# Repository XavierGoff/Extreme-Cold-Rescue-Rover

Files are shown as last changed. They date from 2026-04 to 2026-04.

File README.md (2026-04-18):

# Extreme Cold Rescue Rover

A tracked rescue robot designed to operate in snowy and unstable terrain, with a focus on low ground pressure, robust mobility, and practical field deployment. This project was developed as a fast-turnaround engineering build, combining mechanical design, drivetrain selection, power system integration, and control architecture into a compact rescue platform.

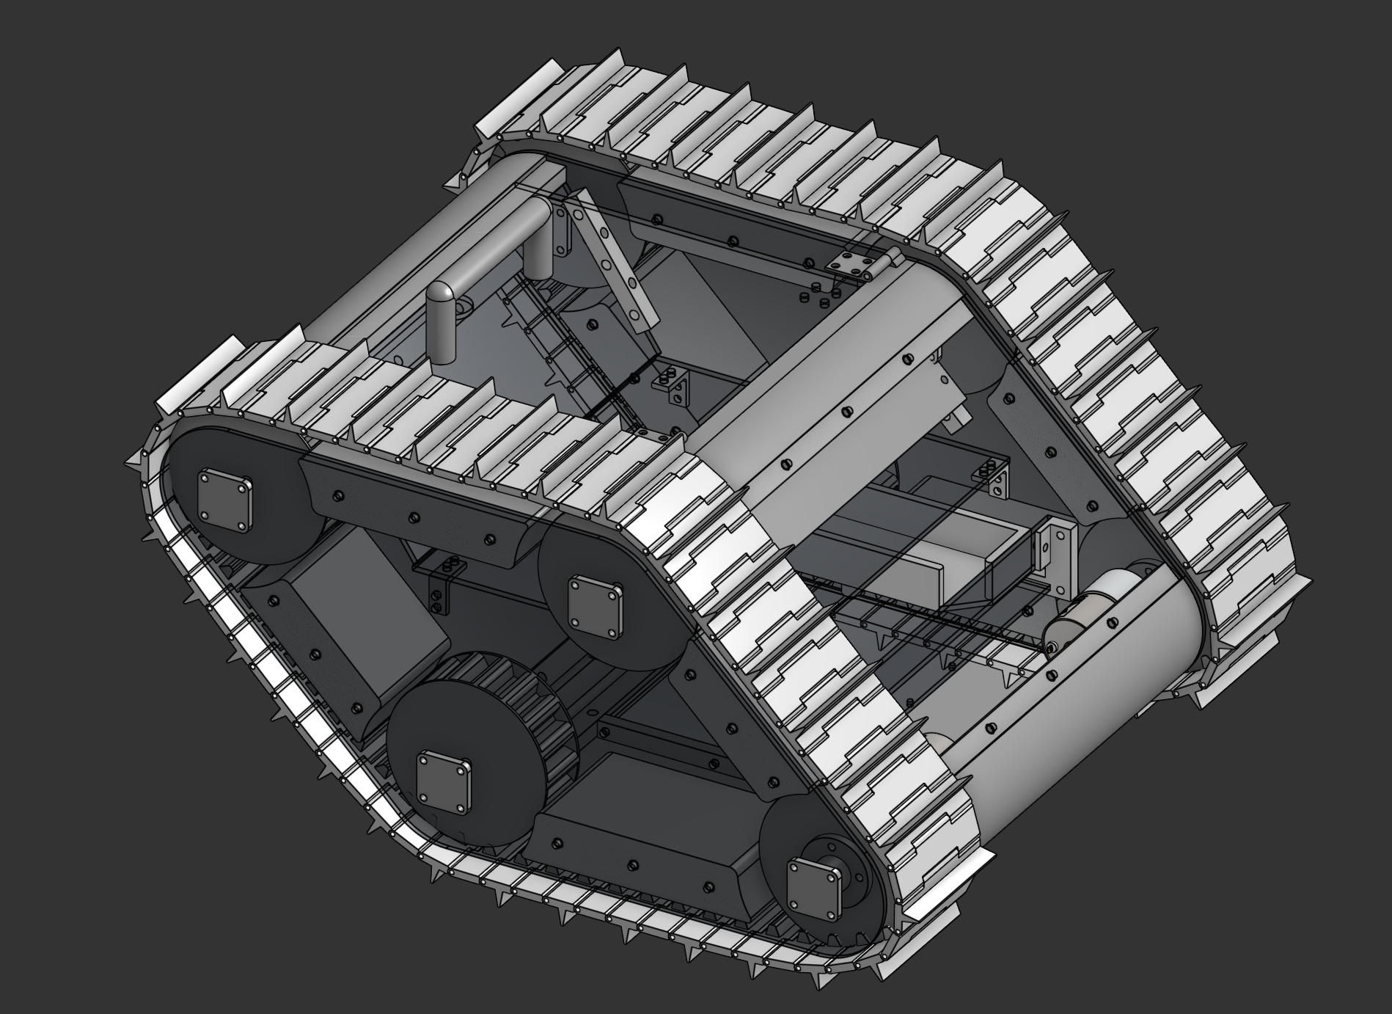
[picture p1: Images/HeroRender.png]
Hero Render


## Overview

This robot was developed to address a simple but difficult problem: how can a small ground robot move effectively across soft snow without sinking, stalling, or becoming unstable?

The project focuses on designing a lightweight tracked platform capable of traversing powdery terrain while carrying its own electronics and drive system. The design process involved balancing traction, footprint area, chassis weight, torque requirements, and manufacturability under tight time and budget constraints.

Rather than treating this as just a remote-controlled vehicle, the project was approached as an engineering system, with attention given to terrain interaction, drivetrain performance, structural layout, and future expandability toward autonomous rescue functionality.

## Key Features

- Tracked drivetrain for improved traction and terrain conformity
- Wide contact area to reduce ground pressure on soft snow
- High-torque drive system for low-speed force output
- Compact chassis designed around integrated electronics and battery packaging
- Modular structure to support iterative redesign and component replacement
- Remote control operation, with future scope for semi-autonomous behaviour

## Engineering Objectives

The main technical goals of the project were:

- Minimise sinking in soft snow by increasing contact area and lowering pressure on the terrain
- Generate sufficient drive torque to maintain motion under resistive snow loading
- Keep overall mass low enough to preserve flotation and reduce drivetrain demand
- Package the electronics cleanly and reliably within the vehicle footprint
- Build a platform that could realistically be expanded into a more capable rescue system

## Design Approach

The design was driven by the interaction between terrain mechanics and drivetrain requirements.

Soft snow presents a major mobility challenge because small wheels or narrow tracks create high local pressure, causing the vehicle to sink and lose usable traction. To address this, the robot uses a tracked architecture with an enlarged footprint, distributing its weight over a greater contact area.

Alongside flotation, the drive system had to be selected for torque rather than top speed. Since snow traversal creates significant rolling and pushing resistance, the drivetrain was designed around high-torque motors capable of moving the platform steadily under load.

The chassis was laid out to keep mass centralised, protect components, and allow quick design iteration as the build evolved.

## Mechanical Design

### Chassis

The robot uses a compact chassis approximately 300 mm × 250 mm in plan, designed to support the drivetrain, electronics, and battery while maintaining a stable centre of mass.

Key design considerations included:

- structural rigidity without unnecessary mass
- sufficient internal space for electronics routing
- accessible mounting points for rapid redesign
- compatibility with 3D printed and fabricated components

### Mobility System

The tracked configuration was chosen over wheels to improve performance on soft terrain.

Advantages of the tracked system include:

- larger contact patch
- reduced ground pressure
- improved traction on loose terrain
- better ability to traverse uneven or partially compacted surfaces

Track width and footprint were treated as major design variables because they directly influence flotation and terrain loading.

## Electronics and Control

The robot integrates a compact control and power architecture designed for reliable drivetrain operation.

Current system elements include:

- microcontroller / receiver interface
- motor driver
- battery power distribution
- switching and protection hardware
- dual drive motor configuration

The control system was selected to prioritise robustness and simplicity in the first build phase, with future scope for more advanced sensing and autonomy.

## Power System

The power system was designed around the demands of the drivetrain, since motor load dominates total energy usage in snow-traversing platforms.

Important design considerations included:

- supplying sufficient current during startup and stall-like conditions
- separating control logic from motor power where necessary
- protecting the system with appropriate switching and fuse selection
- maintaining reasonable runtime without excessive battery mass

## Calculations and Engineering Reasoning

A major part of the project involved validating design decisions analytically rather than selecting components blindly.

The engineering work included:

- estimating ground pressure based on robot mass and contact area
- assessing whether the platform would remain above soft snow rather than digging in
- evaluating torque and drivetrain requirements for snow resistance
- comparing motor options based on speed, torque, and mass trade-offs
- considering the effect of battery and electronics weight on total system performance

Further details are included in the project documents in the [`docs/`](docs/) folder.

## Challenges

Some of the key engineering challenges in this build were:

- balancing torque and weight within a limited budget
- designing for snow performance without overbuilding the chassis
- packaging electronics cleanly in a compact tracked layout
- maintaining modularity while still achieving structural rigidity
- selecting components that were realistic to source and build around quickly

## Future Improvements

Planned next steps include:

- optimised motor torque/speed tradeoff
- improved environmental sealing for wet and cold operation
- sensor integration for terrain awareness and navigation
- use of metal parts for increased lifespan/resiliance
- more rigorous field testing in snow and loose terrain
- semi-autonomous or waypoint-based rescue capability

## Repository Structure

```text
.
├── README.md
├── Main Assembly
├── Cad/
├── Code/
├── Electronics/
├── Images/
└── Docs/

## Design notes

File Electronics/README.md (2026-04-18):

# Electronics Overview

## Introduction

The electronics system integrates control, communication, and power delivery for the robot. It is designed to provide reliable motor actuation while maintaining stable wireless communication under electrically noisy conditions.

---

## System Components

The system consists of:

* ESP32 (receiver and control unit)
* Arduino Nano (transmitter)
* nRF24L01 modules (wireless communication)
* Motor driver (RC PWM input)
* LiPo battery
* Buck converter for regulated logic power

---

## Architecture

The electronics are divided into two main subsystems:

### 1. Control & Communication

* Wireless link using nRF24 modules
* Joystick input processed by Arduino Nano
* Control data transmitted to ESP32

### 2. Power & Actuation

* Motor driver powered directly from battery
* ESP32 and RF modules powered via regulated 5V supply
* PWM signals used to control motor speed and direction

---

## Design Priorities

The electronics were designed with the following priorities:

* Stable wireless communication
* Noise isolation between motors and logic
* Simple and reliable control architecture
* Ease of debugging and modification

---

## Key Challenges

During development, several issues were encountered:

* RF instability due to power noise
* ESP32 serial corruption under load
* Sensitivity of SPI communication to wiring and pin selection

These were addressed through improved grounding, power filtering, and pin configuration.

---

## Summary

The final electronics system provides a stable platform for wireless teleoperation, while remaining modular and extensible for future upgrades such as sensors or autonomous control.

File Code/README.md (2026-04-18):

# Code

## Overview

This folder contains the embedded code used to operate the robot’s wireless control system. The firmware is split into two independent components:

* **Transmitter (Arduino Nano)** — reads joystick input and sends control data
* **Receiver (ESP32)** — receives data and drives the motors

The system uses nRF24L01 modules for low-latency wireless communication.

---

## Structure

```text
Firmware/
├── ESP32_Receiver/
│   └── main.ino
├── Nano_Transmitter/
│   └── main.ino
```

---

## ESP32 Receiver

The ESP32 acts as the main control unit on the robot.

### Responsibilities:

* Receive wireless packets from the transmitter
* Interpret joystick inputs
* Apply control logic (differential drive mixing)
* Generate PWM signals for the motor driver
* Implement failsafe behaviour if signal is lost

### Key Features:

* Differential drive mapping (Y ± X)
* Deadzone filtering
* Signal timeout failsafe
* Servo-style PWM output (RC motor driver compatible)

---

## Arduino Nano Transmitter

The transmitter reads user input and sends it wirelessly.

### Responsibilities:

* Read analog joystick inputs
* Map raw values to a usable control range (-255 to 255)
* Apply deadzone filtering to remove noise
* Transmit data packets via nRF24

### Key Features:

* Lightweight control loop
* Consistent update rate (~20–25 Hz)
* Minimal processing to reduce latency

---

## Communication Protocol

Both transmitter and receiver share a common data structure:

```cpp
struct Data_Package {
  int16_t xValue;
  int16_t yValue;
};
```

* `xValue` → turning input
* `yValue` → forward/backward input

Communication is handled using the RF24 library over SPI.

---

## Dependencies

* RF24 library
* SPI library
* ESP32Servo (receiver only)

---

## Upload Instructions

### ESP32:

* Select correct ESP32 board in Arduino IDE
* Ensure correct COM port is selected
* Upload receiver code

### Arduino Nano:

* Select Arduino Nano board
* Choose correct processor (ATmega328P / Old Bootloader if needed)
* Upload transmitter code

---

## Notes

* Both devices must use the same RF address
* SPI wiring must be correct for communication to work
* Power stability is critical for reliable operation

---

## Summary

The firmware is designed to be simple, robust, and responsive, providing a solid foundation for real-time teleoperation while remaining extensible for future features such as autonomy or sensor integration.

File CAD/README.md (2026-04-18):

# CAD

## Overview

This folder contains the mechanical design files for the robot, including structural components, drivetrain layout, and full assembly models.

The CAD work focuses on creating a compact, lightweight chassis capable of supporting a tracked drivetrain while housing the electronics and power system.

---

## Structure

```text
CAD/
├── 3D Printed Parts/
├── Laser Cut Parts/
├── Main Assembly/
```

---

## Design Approach

The mechanical design was developed with the following priorities:

* Low overall mass to improve flotation on soft terrain
* Sufficient structural rigidity to support drivetrain loads
* Efficient packaging of electronics within a compact footprint
* Modularity to allow rapid iteration and redesign

---

## Chassis Design

The chassis is approximately 300 mm × 250 mm in plan and serves as the central structure for:

* Motor mounting
* Track support
* Electronics integration
* Battery placement

The layout aims to keep mass centralised and maintain a stable centre of gravity.

---

## Drivetrain Integration

The CAD model incorporates a tracked system designed to maximise ground contact area.

Key considerations:

* Track width and footprint for reduced ground pressure
* Motor placement for efficient power transmission
* Clearance for debris and snow accumulation

---

## Manufacturing Methods

The design is intended for rapid prototyping using:

* **3D printing (FDM)** for custom components
* **Laser cutting** for flat structural parts
* Standard fasteners (M3 hardware) for assembly

---

## Assembly

The `Main Assembly` folder contains the full system model, showing:

* Component placement
* Mounting relationships
* Overall packaging of the robot

This assembly is used to verify fit, clearances, and integration between subsystems.

---

## Notes

* Parts are designed with tolerances suitable for typical FDM printers
* Fillets and chamfers are used where appropriate to reduce stress concentrations
* The design supports iterative updates without requiring a full rebuild

---

## Future Improvements

* Increased use of metal components for durability
* Improved sealing for wet and cold environments
* Optimisation of track geometry
* Refined mounting solutions for electronics

---

## Summary

The CAD design provides a practical and adaptable mechanical foundation for the robot, balancing performance, manufacturability, and ease of iteration.

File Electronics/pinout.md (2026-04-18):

# Pinout Reference

## ESP32 (Receiver)

| Function | Pin |
| --- | --- |
| CE | GPIO 4 |
| CSN | GPIO 5 |
| SCK | GPIO 18  |
| MOSI | GPIO 23  |
| MISO | GPIO 19  |
| Motor Left (RC1)  | GPIO 16  |
| Motor Right (RC2) | GPIO 17  |
| 5V Power | VIN / 5V |
| Ground | GND |

---

## Arduino Nano (Transmitter)

| Function | Pin |
| --- | --- |
| CE | D4  |
| CSN | A7  |
| SCK | D13 |
| MOSI | D11 |
| MISO | D12 |
| Joystick X | A0  |
| Joystick Y | A1  |
| 5V Power | 5V  |
| Ground | GND |

---

## Joystick Module

| Function | Connection |
| --- | --- |
| VCC | 5V |
| GND | GND |
| VRx | A0 |
| VRy | A1 |

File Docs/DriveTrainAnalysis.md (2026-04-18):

# Drivetrain Analysis

## Overview

The drivetrain was designed to enable reliable motion across soft, low-strength terrain such as powder snow. The primary challenges were maintaining traction while preventing the robot from sinking.

---

## Terrain Interaction

Soft snow behaves as a deformable surface:

* High local pressure causes sinking
* Low pressure allows the robot to remain on top

Therefore, drivetrain design must minimise ground pressure.

---

## Ground Pressure Considerations

Ground pressure is defined as:

```text
Pressure = Weight / Contact Area
```

To reduce pressure:

* Increase contact area
* Reduce total mass

---

## Tracked Configuration

Tracks were selected to maximise contact area.

Advantages:

* Large footprint distributes weight
* Improved traction through continuous contact
* Better performance on uneven surfaces

---

## Trade-offs

Tracked systems introduce:

* Increased mechanical friction
* Higher power requirements
* More complex construction

However, these were acceptable given the terrain requirements.

---

## Torque Requirements

Snow creates significant resistance through:

* compression of material
* ploughing effect at the front of the track

This requires:

* high torque at low speeds
* stable drivetrain output

---

## Motor Selection

Motors were chosen based on:

* torque output rather than speed
* ability to operate under load without stalling

Gear reduction plays a key role in increasing usable torque.

---

## Turning Behaviour

Differential drive introduces:

* skid steering (tracks slide during turns)
* increased resistance during rotation

This was accepted as a trade-off for simplicity.

---

## Weight Distribution

Mass was kept:

* low
* centrally located

This improves:

* stability
* uniform load distribution across tracks

---

## Summary

The drivetrain design prioritises:

* flotation over speed
* torque over efficiency
* simplicity over precision

This results in a system capable of traversing challenging terrain while remaining mechanically feasible to build.

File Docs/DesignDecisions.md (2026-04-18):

# Design Decisions

## Overview

This project was driven by a series of practical engineering trade-offs, balancing performance, complexity, cost, and build time. Each major component was selected based on its suitability for the specific constraints of snow traversal and rapid prototyping.

---

## Tracked vs Wheeled Locomotion

### Decision: Tracked drivetrain

Tracked locomotion was selected over wheels due to its superior performance in soft terrain.

**Reasons:**

* Increased contact area reduces ground pressure
* Improved traction on loose or uneven surfaces
* Better load distribution across the terrain

**Trade-offs:**

* Increased mechanical complexity
* Higher friction losses compared to wheels
* More difficult turning dynamics

Despite these drawbacks, tracks were necessary to achieve reliable mobility in snow.

---

## Microcontroller Selection

### Decision: ESP32 (receiver), Arduino Nano (transmitter)

A dual-microcontroller architecture was used.

**ESP32 (receiver):**

* Greater processing capability
* More flexible GPIO
* Better suited for handling communication and motor control simultaneously

**Arduino Nano (transmitter):**

* Simple and reliable
* Sufficient for reading joystick inputs
* Lower complexity for the user interface side

This separation reduces system coupling and simplifies debugging.

---

## Communication Protocol

### Decision: nRF24L01 over Bluetooth/WiFi

**Reasons:**

* Lower latency than WiFi-based solutions
* Simpler communication model (no pairing or network setup)
* More predictable performance in isolated environments

**Trade-offs:**

* Less range than some long-range protocols
* Requires careful power and wiring management

The nRF modules provided a good balance between simplicity and responsiveness.

---

## Motor Driver Selection

### Decision: RC-style motor driver (PWM input)

**Reasons:**

* Simplifies control (servo-style signals)
* Eliminates need for custom H-bridge logic
* Reliable and well-tested interface

**Trade-offs:**

* Less control granularity compared to direct PWM + direction control
* Requires calibration around neutral (1500 µs)

---

## Power Architecture

### Decision: Separate motor and logic power paths

**Reasons:**

* Motors introduce electrical noise and voltage drops
* Logic systems (ESP32, RF module) require stable voltage

By separating these paths, system stability was significantly improved.

---

## Control Strategy

### Decision: Differential drive mixing

**Reasons:**

* Simple to implement
* Intuitive user control
* No need for complex kinematic modelling

This approach allows the robot to be controlled effectively with minimal computation.

---

## System Complexity vs Reliability

A key guiding principle was:

> Prioritise reliability over complexity in early iterations

Rather than implementing advanced features (autonomy, sensors), the focus was placed on:

* stable communication
* robust power delivery
* predictable mechanical performance

This ensured a working system before adding additional layers of complexity.

---

## Summary

The design decisions reflect a pragmatic approach:

* Choose solutions that are **good enough and reliable**
* Avoid unnecessary complexity in early builds
* Prioritise system integration over individual component optimisation

These principles enabled rapid development while maintaining engineering rigor.

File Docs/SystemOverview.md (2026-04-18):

# System Overview

## Introduction

The system is designed as a modular, wireless ground robot platform capable of remote operation in low-traction environments. It integrates mechanical, electrical, and control subsystems into a cohesive architecture, prioritising robustness and real-time responsiveness over complexity.

---

## System Architecture

The robot is composed of three primary subsystems:

1. **Transmitter (Human Interface)**
2. **Wireless Communication Layer**
3. **Receiver + Actuation System**

These subsystems operate in a continuous loop, enabling real-time teleoperation.

---

## Data Flow

The control pipeline is structured as follows:

```text
Joystick Input → Arduino Nano → nRF24 Transmitter
              → Wireless Link →
ESP32 Receiver → Control Mapping → Motor Driver → Motors
```

* The joystick generates analog signals corresponding to user input.
* These signals are processed and transmitted wirelessly.
* The receiver interprets the data and converts it into motor commands.

---

## Transmitter Subsystem

The transmitter is built around an Arduino Nano and a dual-axis joystick.

Responsibilities:

* Reading analog joystick inputs
* Converting raw values into a normalised control range (-255 to 255)
* Applying a deadzone to eliminate noise around the neutral position
* Packaging and transmitting data via the nRF24 module

This subsystem is intentionally lightweight to minimise latency and complexity.

---

## Communication System

Wireless communication is handled using nRF24L01 modules operating over SPI.

Key characteristics:

* Low-latency communication
* Simple packet-based transmission
* No reliance on external infrastructure (unlike WiFi)

The system transmits compact data packets containing only the required control variables, ensuring fast and reliable updates.

---

## Receiver and Control Subsystem

The receiver is based on an ESP32 microcontroller.

Responsibilities:

* Receiving incoming control packets
* Validating signal timing (failsafe timeout)
* Mapping joystick input into differential motor commands
* Generating PWM signals for the motor driver

A signal timeout mechanism ensures that the robot halts if communication is lost.

---

## Control Strategy

The control system uses a differential drive model:

* Forward/backward motion is controlled by the Y-axis
* Turning is controlled by the X-axis
* Motor commands are generated using a simple mixing algorithm:

```text
Left Motor  = Y + X
Right Motor = Y - X
```

This allows for intuitive control and smooth transitions between motion states.

---

## Power System Integration

The system separates high-current motor power from logic-level electronics:

* Motors are powered directly from the battery
* Control electronics are powered via a regulated supply

This reduces electrical noise and improves system stability.

---

## Summary

The system architecture prioritises:

* Simplicity and reliability
* Real-time control
* Modular expandability

The result is a robust platform that can be extended with additional sensing and autonomy in future iterations.

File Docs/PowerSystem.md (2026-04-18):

# Power System

## Overview

The power system was designed to support two fundamentally different load types:

1. High-current, noisy motor loads
2. Low-power, sensitive control electronics

Managing these together required careful separation and stabilisation.

---

## System Architecture

```text
Battery
│
├── Motor Driver (direct supply)
│
└── Buck Converter → ESP32 + nRF modules
```

---

## Battery Selection

A LiPo battery was chosen due to:

* High energy density
* Ability to supply large currents
* Compact size relative to capacity

The battery must support peak motor current, especially during startup and stall conditions.

---

## Motor Power Path

Motors are powered directly from the battery.

**Reasons:**

* Avoids unnecessary voltage conversion losses
* Ensures maximum available current
* Simplifies wiring for high-current paths

---

## Logic Power Path

Control electronics are powered through a buck converter.

**Reasons:**

* ESP32 and RF modules require regulated voltage
* Direct battery voltage would exceed safe limits
* Stable voltage improves communication reliability

---

## Electrical Noise and Stability

A major challenge in the system was electrical noise generated by motors.

Effects observed:

* Serial communication corruption
* RF instability
* Microcontroller resets

---

## Mitigation Strategies

Several measures were implemented:

### Capacitive Filtering

* Capacitors placed across RF module supply
* Additional bulk capacitance on logic power rail

### Power Separation

* Isolated motor and logic supply paths

### Grounding

* Common ground maintained across all components
* Minimised ground loops and floating references

---

## Switching and Protection

* Inline fuse used for overcurrent protection
* Manual switch used for system power control

---

## Key Lessons

* Motor noise can significantly affect digital systems
* Power stability is critical for reliable wireless communication
* Even simple systems require careful electrical design under load

---

## Summary

The final power system balances:

* High current capability for motors
* Stable, clean supply for control electronics

This separation was essential to achieving reliable operation.

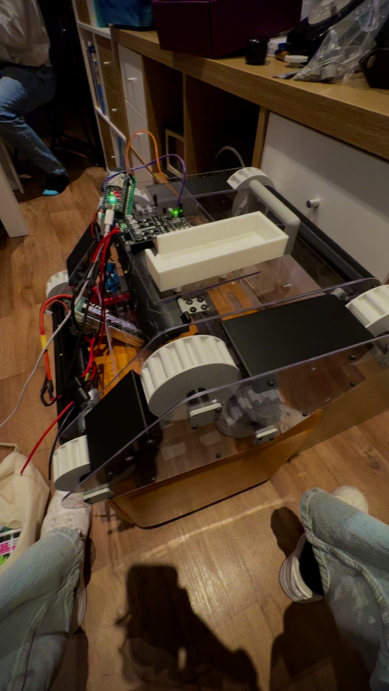
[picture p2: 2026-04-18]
Images/Completed Electronics.jpg

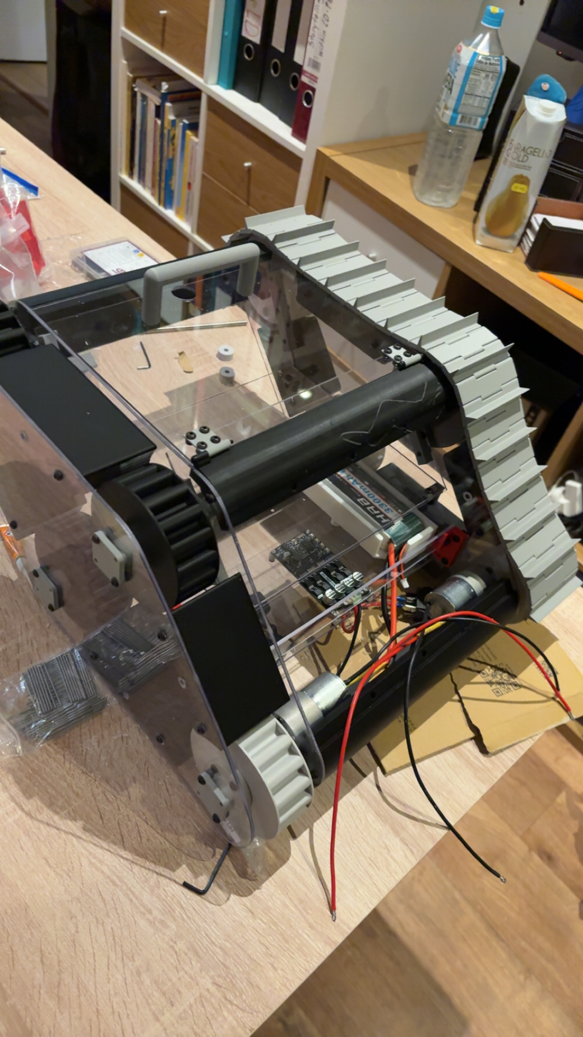
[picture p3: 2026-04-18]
Images/Starting Electronics.JPG

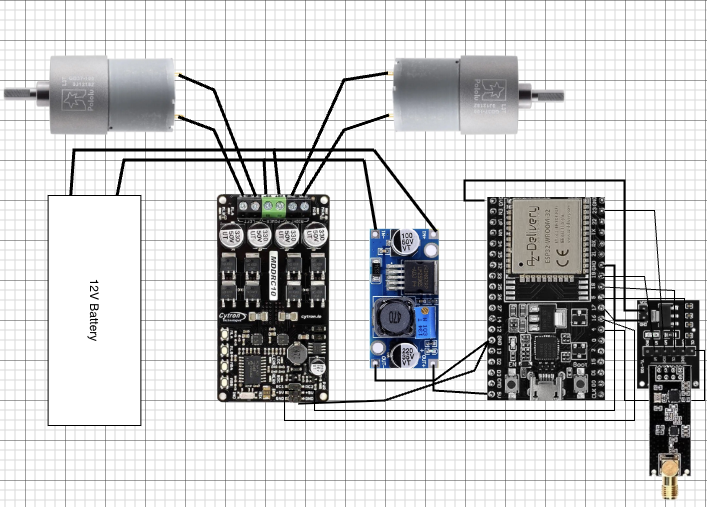
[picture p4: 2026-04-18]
Electronics/Robot Electronics Diagram.png

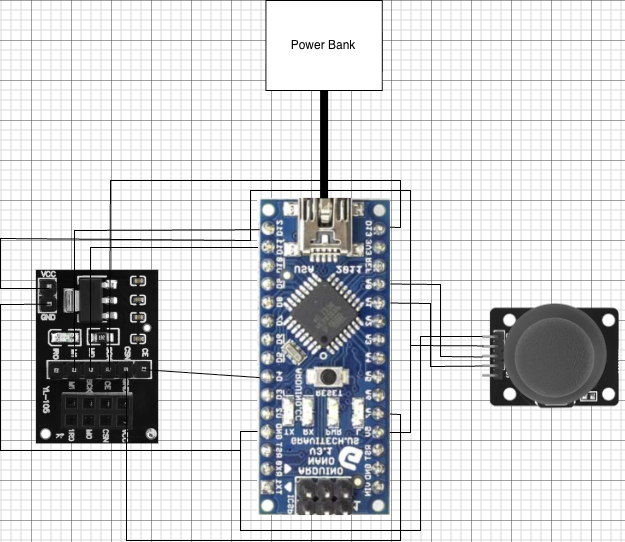
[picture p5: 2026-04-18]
Electronics/Controller Electronics Diagram.drawio.png

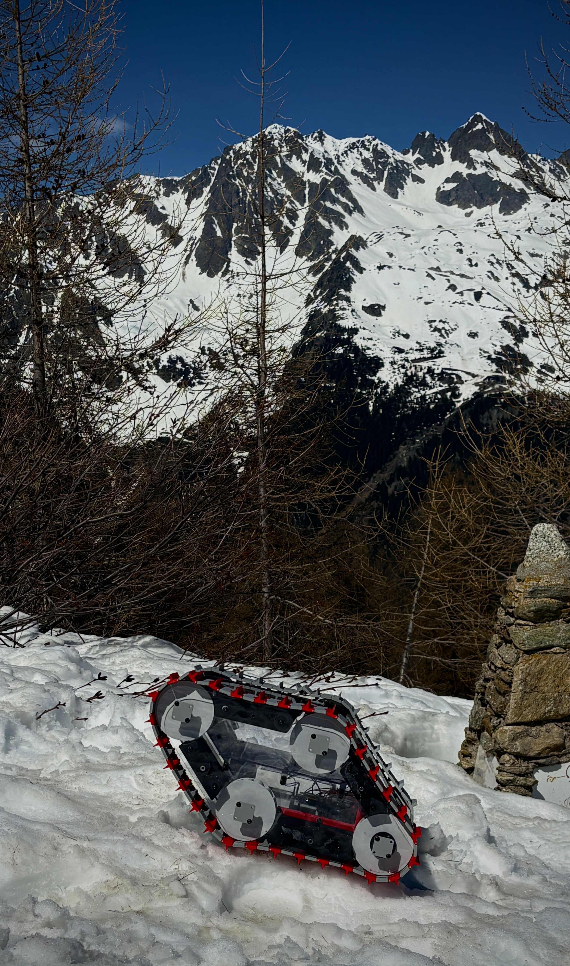
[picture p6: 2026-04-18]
Images/Robot on the snow.jpg

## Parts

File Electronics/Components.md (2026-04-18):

# Components List

## Core Electronics

* ESP32 Development Board
* Arduino Nano
* nRF24L01 Wireless Modules (x2)
* nRF24L01 Adapter Boards (x2)

---

## Power System

* 11.1V LiPo Battery
* LM2596 Buck Converter
* Inline Blade Fuse (15A)
* Power Switch

---

## Actuation

* Cytron Motor Driver (RC PWM Input)
* 2 × DC Gear Motors

---

## Input

* Dual-axis joystick module

---

## Supporting Components

* Electrolytic capacitors (10µF – 470µF)
* Jumper wires
* XT60 connectors
* Perfboard (for mounting electronics)

---

## Notes

Components were selected based on:

* availability
* cost constraints
* compatibility with rapid prototyping

Where possible, off-the-shelf modules were used to reduce development time and complexity.

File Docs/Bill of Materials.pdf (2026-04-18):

Name | Quantity | Link | Price | Total
EVA foam | 4 | https://www.amazon.co.uk/Do%C2%B2ping-Premium-Cosplay-35x150cm-Projects/dp/B0CNVPV3Y6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 £22.00 | £88.00
10A 2-Channel 7-30V DC
Motor Driver for RC | 1 | https://thepihut.com/products/10a-2-channel-7-30v-dc-motor-driver-for-rc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 £36.80 | £36.80

Pololu 12V 100:1 37D 12V
Metal Gearmotor | 2 | https://thepihut.com/products/pololu-12v-100-1-37d-12v-metal-gearmotor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
| | | £37.40 | £74.80
3S LiPo Battery (2200mAh
11.1V) | 1
https://www.sundonmodelshop.com/products/lipo-3s-2200mah-11-1v-30c-deans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 £17.50 | £17.50
LiPo Balance Charger | 1 | https://www.modelsport.co.uk/product/1379918?utm_source=chatgpt.com £17.09 | £17.09
ESP32 Dev Board | 1 | https://www.amazon.co.uk/ESP32-DevKitC-Development-Unassembled-Microcontroller-Esp32-devkitc-32e/dp/B0CX1BPJ41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 £6.09 | £6.09
Arduino Nano (clone) | 1 | https://www.amazon.co.uk/Electrones-Board-ATmega328P-Microcontroller-Pre-Soldered/dp/B0DTZ43W2F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 £6.00 | £6.00

nRF24L01 PA/LNA Long
Range Module | 2
https://www.amazon.co.uk/NRF24L01-Wireless-Transceiver-Communication-Antenna/dp/B0D98RD52Z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 £4.56 | £9.12
nRF24 Adapter Board | 2 | https://www.amazon.co.uk/AZDelivery-NRF24L01-Transceiver-Compatible-Raspberry/dp/B086TTZG94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 £4.50 | £9.00
LM2596 Buck Converter | 1 | https://www.amazon.co.uk/1-25V-35V-converter-adjustable-Attractive-processing/dp/B0FTFYBZJC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 £2.71 | £2.71
Joystick Module | 1 | https://www.amazon.co.uk/AZDelivery-Joystick-Breakout-Arduino-including/dp/B07CKCBHF4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 £7.50 | £7.50
Power Switch (≥15A) | 1 | https://www.amazon.co.uk/Function-Forward-Reverse-Rolling-Shutters/dp/B0F4RR7M3L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 £6.50 | £6.50
Inline Fuse Holder | 1 | https://www.screwfix.com/p/pearl-consumables-30a-12v-mini-blade-inline-fuse-holder/835YY?utm £2.69 | £2.69
15A Blade Fuse | 2 | https://www.halfords.com/technology/car-audio/stereo-fittings/autoleads-blade-add-a-fuse-576436.html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 £8.69 | £17.38
16–18 AWG Wire (power) | 1 | https://www.amazon.co.uk/Gruiqrd-Gauge-Silicone-Flexible-Impedance/dp/B0CZRGQDKF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 £9.50 | £9.50
22–26 AWG Wire (signal) | 1 | https://www.amazon.co.uk/AYWFEY-Stranded-Electrical-Silicone-Electronics/dp/B0F7HQDCZL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 £9.00 | £9.00
XT60 Connectors | 1 | https://www.amazon.co.uk/YIXISI-Connectors-Female-Bullet-Battery-Xt60-Sheath/dp/B0D9T9HZVD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 £9.00 | £9.00
Heat Shrink Pack | 1 | https://www.amazon.co.uk/Heat-Shrink-Tubing-Kit-Waterproof/dp/B0F4N5NK5X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 £2.00 | £2.00
Dupont Jumper Pack | 1 | https://www.amazon.co.uk/Elegoo-120pcs-Multicolored-Breadboard-arduino-colorful/dp/B01EV70C78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 £7.00 | £7.00
Perfboard / Terminal Board | 1 | https://www.amazon.co.uk/Chanzon-Double-Sided-Board-Sizes/dp/B07LF78ZY3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 £9.00 | £9.00
1000µF Capacitor | 1 | https://www.amazon.co.uk/500-Piece-Electrolytic-Capacitor-Assortment-Kit/dp/B0DWX8KXVF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 £15.00 | £15.00
10–47µF Capacitors | 2 | https://www.amazon.co.uk/500-Piece-Electrolytic-Capacitor-Assortment-Kit/dp/B0DWX8KXVF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 £0.00 | £0.00
0.1µF Capacitors | 2 | https://www.amazon.co.uk/500-Piece-Electrolytic-Capacitor-Assortment-Kit/dp/B0DWX8KXVF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 £0.00 | £0.00
100 Threaded M4 inserts | 2 | https://www.accu.co.uk/brass-threaded-inserts/845139-HTBI-M4-BR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 £1.26 | £2.52
Stainless Steel Round Rods | 3 | https://www.amazon.co.uk/dp/B0DFQ219XD?ref=ppx_yo2ov_dt_b_fed_asin_title&th=1 £4.89 | £14.67
M4 Bolts and Nuts Set | 2 | https://www.amazon.co.uk/dp/B0DQ3R9WN6?ref=ppx_yo2ov_dt_b_fed_asin_title&th=1 £6.98 | £13.96
Flexible Silicone Tube | 1 | https://www.amazon.co.uk/dp/B0F3WH1YFY?ref=ppx_yo2ov_dt_b_fed_asin_title&th=1 £7.64 | £7.64
| | | | £400.47

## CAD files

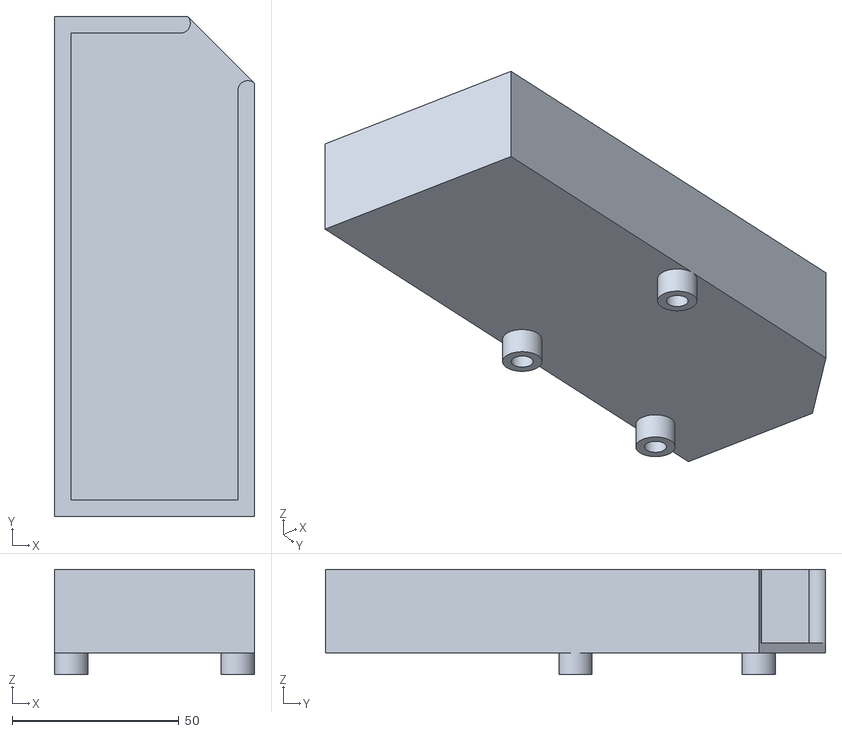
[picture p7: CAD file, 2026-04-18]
CAD/3DP Makeathon/Battery Holder.stl
60.0 x 150.0 x 31.5

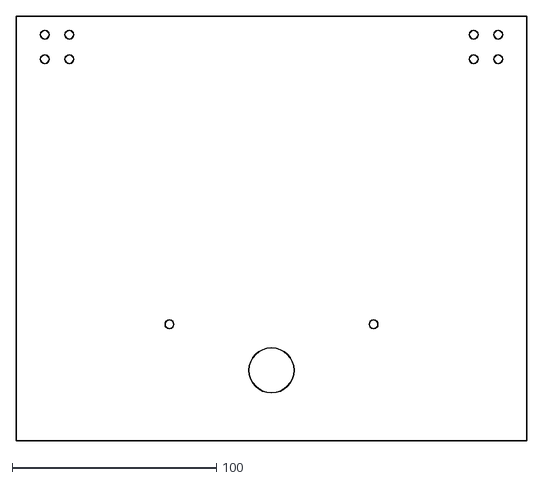
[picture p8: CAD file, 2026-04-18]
CAD/Laser Cut Panels /Hinged Top.dxf
250.0 x 207.9

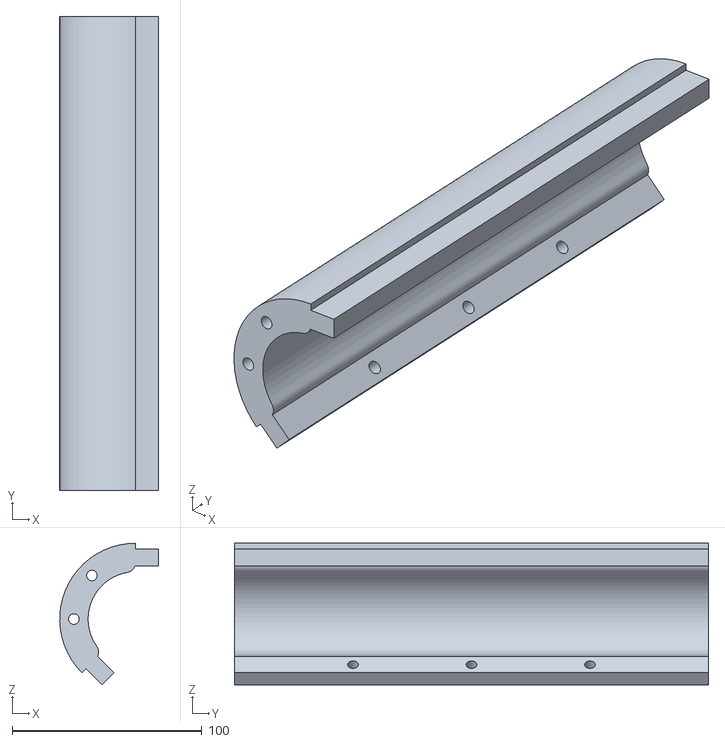
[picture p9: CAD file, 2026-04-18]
CAD/3DP Makeathon/Top Acute Standoff.stl
52.0 x 250.0 x 74.6

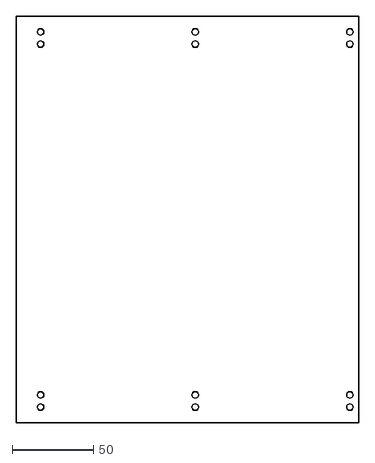
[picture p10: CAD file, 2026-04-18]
CAD/Laser Cut Panels /Package Bottom.dxf
210.5 x 250.0

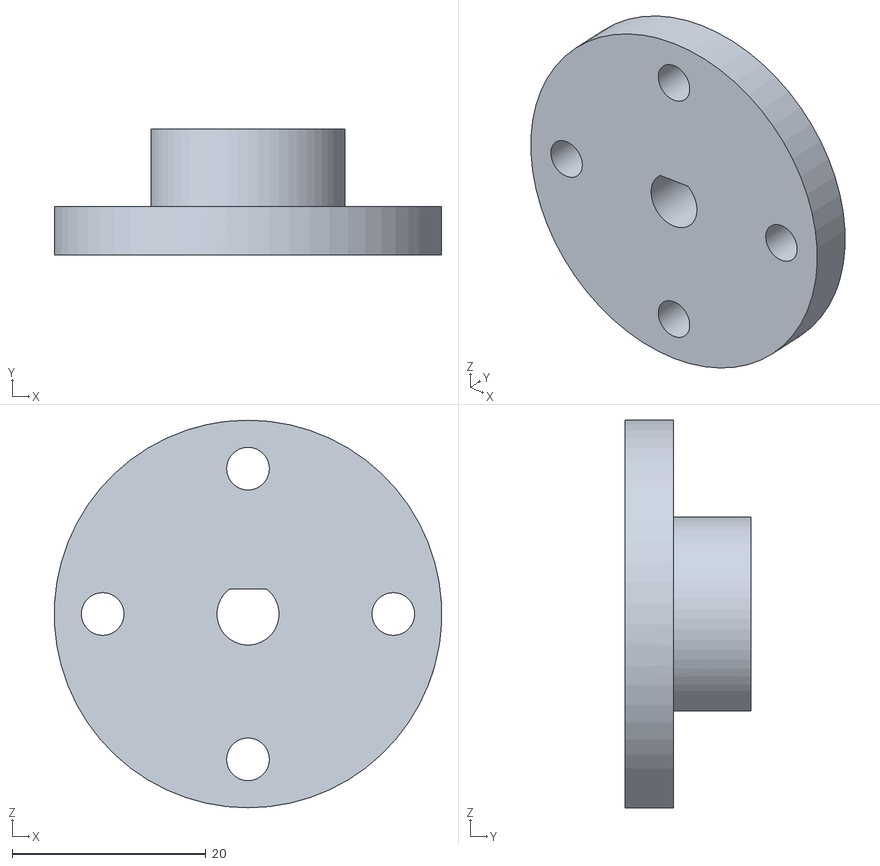
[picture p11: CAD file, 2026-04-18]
CAD/3DP Makeathon/Female Hub.stl
39.9 x 13.0 x 40.0

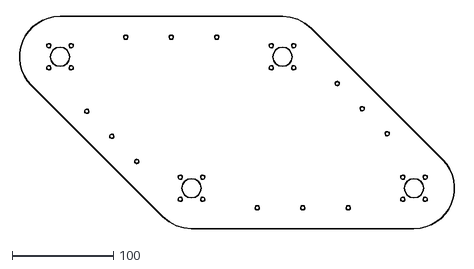
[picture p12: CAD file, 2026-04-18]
CAD/Laser Cut Panels /Outer Panel.dxf
436.3 x 210.0

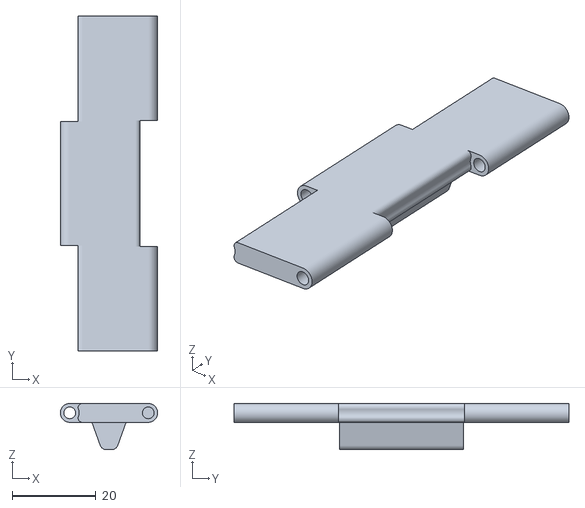
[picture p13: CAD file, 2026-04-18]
CAD/3DP Makeathon/Tread Tracks.stl
23.2 x 80.0 x 11.0

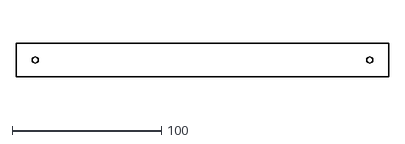
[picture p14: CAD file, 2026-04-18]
CAD/Laser Cut Panels /Electronics Side Strip.dxf
250.0 x 22.5

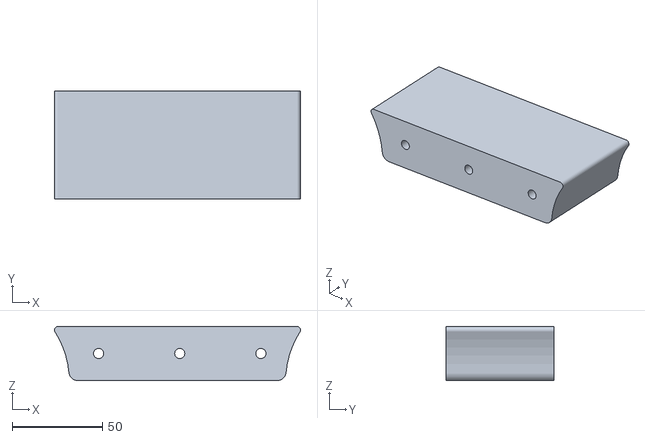
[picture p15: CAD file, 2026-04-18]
CAD/3DP Makeathon/Upper-Lower Standoff.stl
136.4 x 60.0 x 30.0

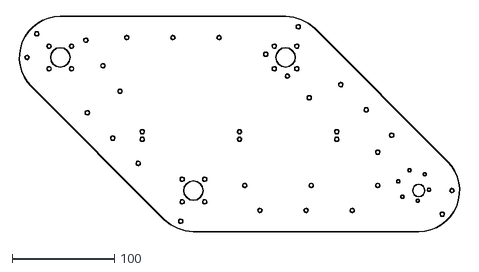
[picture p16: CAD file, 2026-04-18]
CAD/Laser Cut Panels /Inner Panel.dxf
436.3 x 210.0

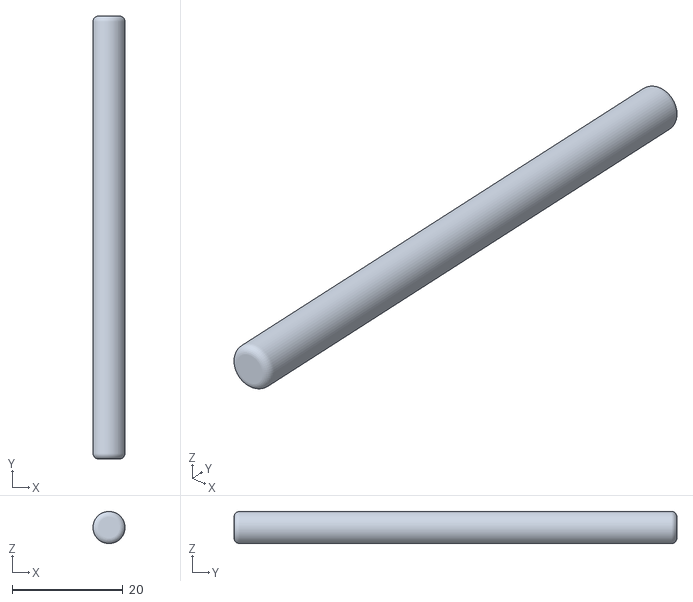
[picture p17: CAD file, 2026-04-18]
CAD/3DP Makeathon/Axel.stl
5.79 x 80.0 x 5.80

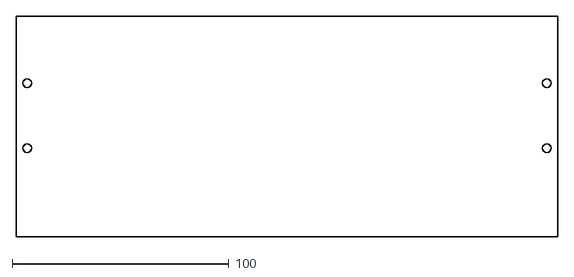
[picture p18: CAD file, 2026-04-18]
CAD/Laser Cut Panels /Package Front.dxf
250.0 x 102.0

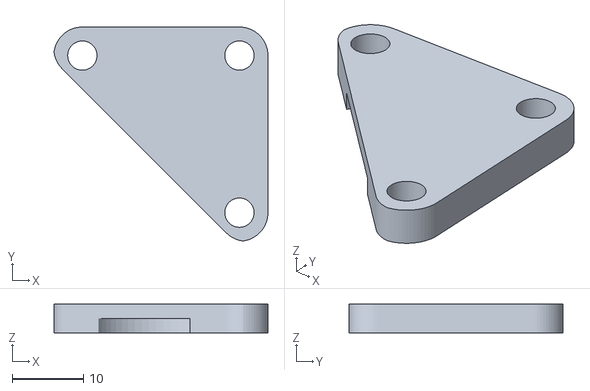
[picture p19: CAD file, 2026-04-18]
CAD/3DP Makeathon/Triangular Bearing Lock.stl
30.0 x 30.0 x 4.00

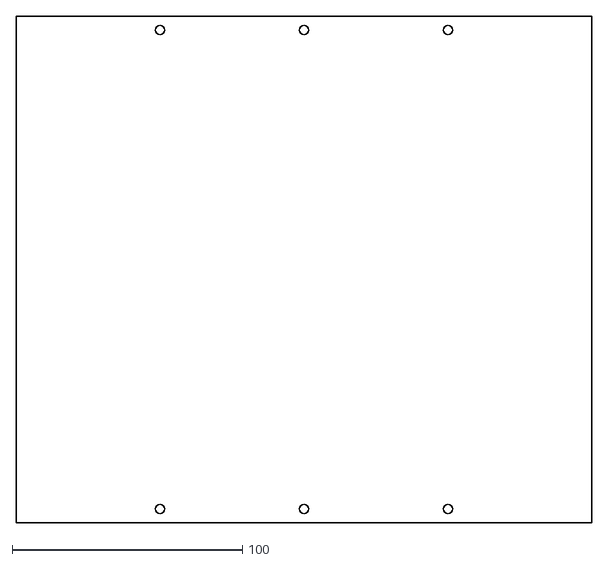
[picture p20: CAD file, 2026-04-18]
CAD/Laser Cut Panels /Top-Bottom Panel.dxf
250.0 x 220.0

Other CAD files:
CAD/3DP Makeathon/Acute Standoff.stl
CAD/Laser Cut Panels /Front-Back Panel.dxf
CAD/3DP Makeathon/Obtuse Standoff.stl
CAD/Laser Cut Panels /Package Back.dxf
CAD/3DP Makeathon/Bearing Lock.stl
CAD/3DP Makeathon/Blocker.stl
CAD/3DP Makeathon/Custom Gear.stl
CAD/3DP Makeathon/Driven Custom Gear.stl
CAD/3DP Makeathon/Electronics Tray Left.stl
CAD/3DP Makeathon/Electronics Tray Right.stl
CAD/3DP Makeathon/Handle.stl
CAD/3DP Makeathon/Hinge.stl
CAD/3DP Makeathon/Hinged Standoff.stl
CAD/3DP Makeathon/Large Spacers.stl
CAD/3DP Makeathon/Male Hub.stl
CAD/3DP Makeathon/Motor Spacer.stl
CAD/3DP Makeathon/Package Cover Mount.stl
CAD/3DP Makeathon/Packet Bracket.stl
CAD/3DP Makeathon/Side Standoffs.stl
CAD/3DP Makeathon/Tread Locking Pins.stl
CAD/3DP Makeathon/Tread Tracks with Plow.stl
CAD/Laser Cut Panels /Electronics Tray.dxf

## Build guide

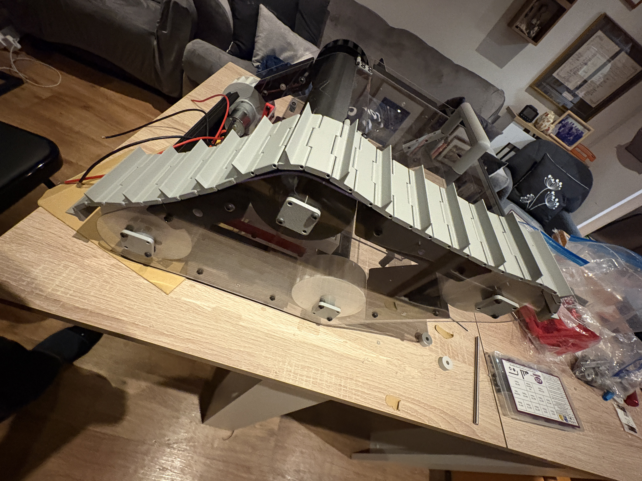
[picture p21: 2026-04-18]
Images/Building .JPG

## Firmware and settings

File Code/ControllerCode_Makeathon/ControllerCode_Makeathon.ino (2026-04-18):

#include <SPI.h>
#include <RF24.h>
#include <stdint.h>

RF24 radio(4, 21);   // CE, CSN
const byte address[6] = "06211";

struct Data_Package {
  int16_t xValue;
  int16_t yValue;
};

Data_Package data;

const int xPin = 34;   // joystick left/right
const int yPin = 35;   // joystick forward/back

const int DEADZONE = 25;

int readAxis(int pin) {
  int raw = analogRead(pin);                 // 0 to 4095
  int val = map(raw, 0, 4095, -255, 255);    // convert to -255 to 255

  if (abs(val) < DEADZONE) val = 0;
  return constrain(val, -255, 255);
}

void setup() {
  Serial.begin(115200);
  delay(1000);

  Serial.println("=== TRANSMITTER BOOT ===");

  if (!radio.begin()) {
    Serial.println("Radio NOT responding!");
    while (1) {
      delay(10);
    }
  }

  radio.setPALevel(RF24_PA_MIN);
  radio.openWritingPipe(address);
  radio.stopListening();

  Serial.println("Transmitter ready");
}

void loop() {
  data.xValue = readAxis(xPin);
  data.yValue = readAxis(yPin);

  bool ok = radio.write(&data, sizeof(Data_Package));

  Serial.print("X: ");
  Serial.print(data.xValue);
  Serial.print("  Y: ");
  Serial.print(data.yValue);
  Serial.print("  | sent: ");
  Serial.println(ok ? "YES" : "NO");

  delay(40);
}

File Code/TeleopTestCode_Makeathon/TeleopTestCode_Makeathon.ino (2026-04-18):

#include <SPI.h>
#include <RF24.h>
#include <ESP32Servo.h>
#include <stdint.h>

// ================= RADIO =================
RF24 radio(4, 5);   // CE, CSN
const byte address[6] = "06211";

struct Data_Package {
  int16_t xValue;
  int16_t yValue;
};

Data_Package data;

// ================= MOTOR DRIVER OUTPUTS =================
Servo leftDrive;
Servo rightDrive;

// Cytron RC inputs
const int RC1_PIN = 16;
const int RC2_PIN = 17;

const int STOP_US = 1500;
const int MAX_OFFSET = 200;
const int DEADZONE = 30;
const unsigned long SIGNAL_TIMEOUT = 300;

unsigned long lastPacketTime = 0;

// Flip these if direction is wrong
const bool invertX = false;
const bool invertY = true;
const bool invertLeft = false;
const bool invertRight = false;

int clamp255(int v) {
  return constrain(v, -255, 255);
}

int applyDeadzone(int v) {
  if (abs(v) < DEADZONE) return 0;
  return v;
}

int toPulseOffset(int v) {
  return map(v, -255, 255, -MAX_OFFSET, MAX_OFFSET);
}

void stopDrive() {
  leftDrive.writeMicroseconds(STOP_US);
  rightDrive.writeMicroseconds(STOP_US);
}

void setup() {
  Serial.begin(115200);
  delay(1000);

  Serial.println("=== ROBOT TELEOP BOOT ===");

  leftDrive.attach(RC1_PIN, 1000, 2000);
  rightDrive.attach(RC2_PIN, 1000, 2000);

  stopDrive();
  delay(3000);  // let driver initialize at neutral

  if (!radio.begin()) {
    Serial.println("Radio NOT responding!");
    while (1) {
      delay(10);
    }
  }

  radio.setPALevel(RF24_PA_MIN);
  radio.openReadingPipe(0, address);
  radio.startListening();

  lastPacketTime = millis();

  Serial.println("Receiver ready");
}

void loop() {
  if (radio.available()) {
    radio.read(&data, sizeof(Data_Package));
    lastPacketTime = millis();

    int x = clamp255(data.xValue);
    int y = clamp255(data.yValue);

    if (invertX) x = -x;
    if (invertY) y = -y;

    x = applyDeadzone(x);
    y = applyDeadzone(y);

    int leftCmd = y + x;
    int rightCmd = y - x;

    leftCmd = clamp255(leftCmd);
    rightCmd = clamp255(rightCmd);

    if (invertLeft) leftCmd = -leftCmd;
    if (invertRight) rightCmd = -rightCmd;

    int leftPulse = STOP_US + toPulseOffset(leftCmd);
    int rightPulse = STOP_US + toPulseOffset(rightCmd);

    leftDrive.writeMicroseconds(leftPulse);
    rightDrive.writeMicroseconds(rightPulse);

    Serial.print("X: ");
    Serial.print(x);
    Serial.print("  Y: ");
    Serial.print(y);
    Serial.print("  | Lpulse: ");
    Serial.print(leftPulse);
    Serial.print("  Rpulse: ");
    Serial.println(rightPulse);
  } else {
    if (millis() - lastPacketTime > SIGNAL_TIMEOUT) {
      stopDrive();
    }
  }
}

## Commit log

2026-04-18 add project files
    [Acute Standoff.stl, Axel.stl, Battery Holder.stl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]
2026-04-18 Organise CAD folder
    [Electronics Side Strip.dxf, Electronics Tray.dxf, Front-Back Panel.dxf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]
2026-04-18 Create System Overview documentation
    Added comprehensive system overview documentation including architecture, data flow, and subsystem responsibilities.
2026-04-18 Add Design Decisions documentation
    Documented design decisions regarding locomotion, microcontroller selection, communication protocol, motor driver selection, power architecture, control strategy, and system complexity.
2026-04-18 Add drivetrain analysis documentation
    Added comprehensive analysis of drivetrain design for soft terrain, covering aspects such as terrain interaction, ground pressure considerations, tracked configuration, trade-offs, torque requirement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
2026-04-18 Add Power System documentation
    Documented the design and considerations of the power system, including architecture, battery selection, power paths, noise mitigation strategies, and key lessons learned.
2026-04-18 Add pinout reference for ESP32 and Arduino Nano
    Added a pinout reference for ESP32, Arduino Nano, and Joystick Module.
2026-04-18 Add components list for electronics project
    Added a comprehensive list of electronic components categorized by their function, including core electronics, power systems, actuation, input, and supporting components, along with selection notes.
2026-04-18 Rename Main Assembly to CAD/Main Assembly
2026-04-18 Add README for CAD design documentation
    This README provides an overview of the CAD design for the robot, detailing the structure, design approach, chassis design, drivetrain integration, manufacturing methods, assembly, notes, future impr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
2026-04-18 Add README for robot control system firmware
    Added detailed README for robot wireless control system, including overview, structure, responsibilities, features, communication protocol, dependencies, and upload instructions.
